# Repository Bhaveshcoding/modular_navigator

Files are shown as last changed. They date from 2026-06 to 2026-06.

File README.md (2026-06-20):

# Modular Navigator

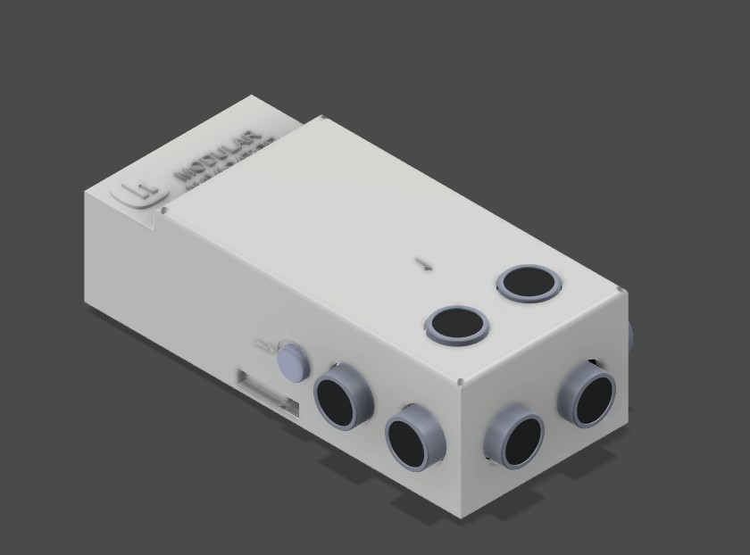
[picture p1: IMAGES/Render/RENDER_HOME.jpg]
Home Render


## Modular Haptic Navigation Device for the Visually Impaired

Modular Navigator is a portable assistive navigation device that provides directional haptic feedback for obstacle awareness.

The system uses four HC-SR04 ultrasonic sensors to monitor the area around the user. Distance measurements are processed by an ESP32, which activates vibration motors corresponding to the detected obstacle direction.

Unlike audio-based navigation aids, the device uses vibration feedback, allowing users to remain aware of surrounding sounds while receiving environmental information.

---

# Project Status

🚧 **Design & Engineering Phase**

Completed:

* CAD enclosure design
* Electronics architecture
* Wiring schematic
* Component selection
* Bill of Materials (BOM)
* Firmware planning
* Wokwi simulation setup
* Manufacturing file preparation

Planned:

* Physical assembly
* Firmware deployment
* Hardware validation
* Real-world testing
* Design iteration

---

# Motivation

Many assistive navigation devices are expensive, difficult to repair, or rely heavily on audio feedback. This project explores a low-cost, open-source alternative that provides directional obstacle awareness through haptic feedback.

The goal is to investigate whether commonly available components, 3D-printed parts, and open-source tools can be used to create a modular navigation aid that is easy to reproduce, modify, and improve.

# Repository Highlights

* Fusion 360 CAD source files
* STEP and STL exports
* ESP32 firmware
* Electronics documentation
* KiCad schematic
* Wiring diagram
* Bill of Materials
* Design journal
* Wokwi simulation
* Build instructions
* Assembly renders and exploded views

---

# Device Overview

The device monitors four directions:

* Front
* Left
* Right
* Downward

When an obstacle is detected, the corresponding vibration motor is activated.

| Hazard | Feedback |
| --- | --- |
| Obstacle on Left | Left vibration motor |
| Obstacle on Right  | Right vibration motor |
| Obstacle Ahead | Front vibration motor |
| Stairs / Drop-offs | Warning vibration pattern |

---

# Fully Assembled Device

## Front Render

Home Render

---

# Interactive 3D Model

[Open Interactive 3D Mesh Grid View](CAD%20files/Model/Model_with%20electronics/ModularNavigator_Enclosure_v1_with_electronics.stl)

The model contains:

* Enclosure
* ESP32
* Battery
* Charging system
* Ultrasonic sensors
* Vibration motors
* Internal mounting structure

---

# System Architecture

## 1. Sensing System

### Components

* 4× HC-SR04 Ultrasonic Sensors

### Coverage

| Sensor | Purpose |
| --- | --- |
| Front | Detect obstacles ahead |
| Left | Detect obstacles on the left  |
| Right | Detect obstacles on the right |
| Downward | Detect stairs and drop-offs |

---

## 2. Processing System

### Controller

* ESP32 Development Board

### Responsibilities

* Read sensor measurements
* Calculate distances
* Determine obstacle direction
* Generate haptic feedback
* Manage overall system operation

---

## 3. Haptic Feedback System

### Components

* 3× Coin Vibration Motors

### Motor Mapping

| Motor | Function |
| --- | --- |
| Left Motor  | Left obstacle warning  |
| Right Motor | Right obstacle warning |
| Front Motor | Front obstacle warning |

---

## 4. Power System

### Components

* 3.7V Li-Po Battery
* TP4056 Charging Module
* MT3608 Boost Converter

### Functions

* Battery charging
* Voltage regulation
* Portable operation

---

# How It Works

1. Ultrasonic sensors emit pulses.
2. Echo times are measured.
3. Distance is calculated by the ESP32.
4. Obstacle direction is determined.
5. Corresponding vibration motor is activated.
6. Feedback is provided to the user.

---

# Exploded Views

## Top Exploded View

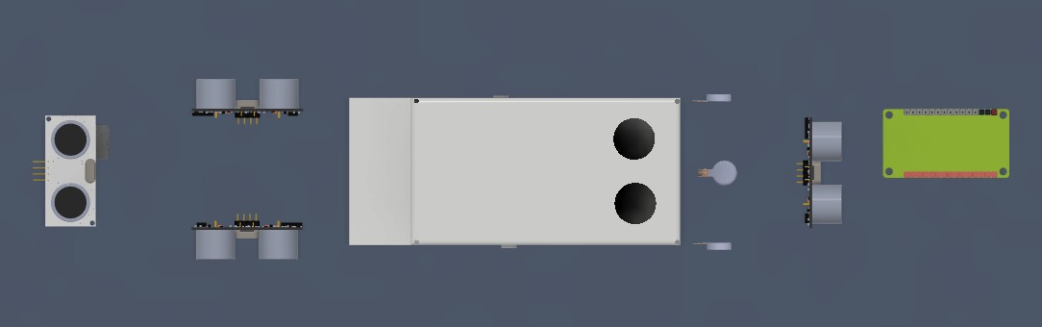
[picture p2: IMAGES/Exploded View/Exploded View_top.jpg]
Exploded Top


## Side Exploded View

Exploded Side

## Home Exploded View

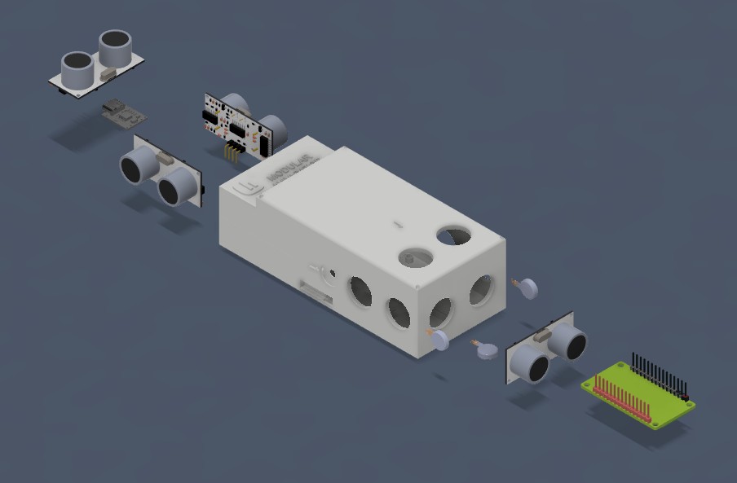
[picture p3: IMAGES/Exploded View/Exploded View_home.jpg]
Exploded Home

# Electronics

## Wiring Diagram

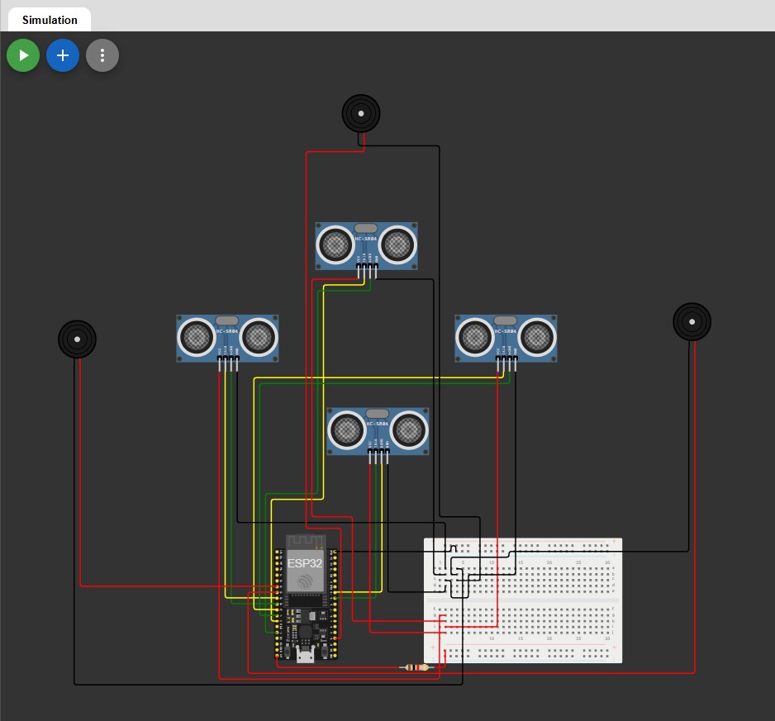
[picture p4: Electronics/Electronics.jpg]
Electronics Map



The wiring diagram documents the complete electrical system, including:

* ESP32 connections
* Ultrasonic sensors
* Vibration motors
* Battery system
* TP4056 charging module
* MT3608 boost converter
* Voltage divider circuits

---

# Hardware Used

| Component | Quantity | Purpose |
| --- | --- | --- |
| ESP32 Dev Board | 1 | Main controller |
| HC-SR04 Sensors | 4 | Obstacle detection  |
| Vibration Motors | 3 | Haptic feedback |
| TP4056 | 1 | Battery charging |
| MT3608 | 1 | Voltage boosting |
| 3.7V Li-Po Battery | 1 | Portable power |
| 2N2222 Transistors | 3 | Motor drivers |
| 1N4007 Diodes | 3 | Flyback protection  |
| Resistors | Multiple | Signal conditioning |

---

# Bill of Materials (BOM)

The complete BOM is available in:

```text
BOM.csv
```

## Total Cost

**$23.93 USD**

The design uses low-cost, commonly available components to keep the project accessible and easy to reproduce.

---

# PCB / Electronics Implementation

The current design uses direct wiring rather than a custom PCB.

Components are mounted inside the enclosure using dedicated mounting features included in the CAD design. Future revisions may use a custom PCB to reduce wiring complexity and improve manufacturability.

---

# Firmware

Firmware location:

```text
FIRMWARE/main.ino
```

Firmware responsibilities:

* Distance measurement
* Obstacle detection
* Direction classification
* Haptic feedback generation
* Continuous environmental monitoring

---

# Wokwi Simulation

Wokwi was used during development to validate the planned system architecture and firmware logic.

### Goals

* Validate GPIO assignments
* Verify sensor behavior
* Test vibration logic
* Debug firmware concepts

### Simulation Link

https://wokwi.com/projects/461725213892270081

---

# How To Build

## Step 1 – Print the Enclosure

Files:

```text
CAD files/Printing Parts/
```

Recommended settings:

* PLA
* 0.2 mm layer height
* 15–20% infill
* Supports where required

---

## Step 2 – Install Components

Install:

* ESP32 Development Board
* HC-SR04 Sensors
* Vibration Motors
* Li-Po Battery
* TP4056 Module
* MT3608 Module

Align all components with the mounting locations shown in the CAD model.

---

## Step 3 – Complete Wiring

Follow:

```text
Electronics/Electronics.md
```

and

```text
Electronics/Electronics.jpg
```

Important notes:

* Use voltage dividers on HC-SR04 ECHO pins.
* Connect all grounds together.
* Verify motor polarity.
* Verify battery polarity before powering the system.

---

## Step 4 – Upload Firmware

Open:

```text
FIRMWARE/main.ino
```

Upload the firmware using Arduino IDE.

Requirements:

* ESP32 board package
* USB cable
* Arduino IDE

---

## Step 5 – Final Assembly

* Route wires through the enclosure.
* Mount the ESP32, sensors, battery, TP4056, and MT3608 using the designed screw mounting points.
* Secure sensors using M1.6 fasteners where required.
* Attach the enclosure lid using M3 screws.
* Verify wiring before powering the device.

---

# Zine

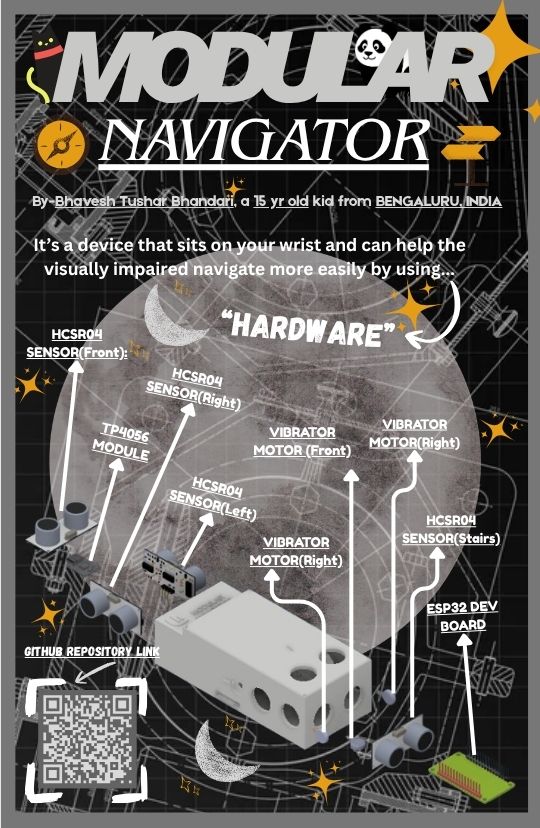
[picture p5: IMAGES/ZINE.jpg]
Zine


The project zine provides a visual overview of the concept and design process.
# Repository Structure

```text
├── CAD files
│   ├── Miscellaneous Parts_&_Images
│   ├── Model/Model_with electronics
│   └── Printing Parts/3D print
│
├── Electronics
│   ├── Electronics.jpg
│   ├── Electronics.md
│   └── Modular_navigator_schematic.kicad_sch
│
├── FIRMWARE
│   └── main.ino
│
├── IMAGES
│   ├── Exploded View
│   ├── Render
│   ├── ZINE.jpg
│   └── ZINE.pdf
│
├── BOM.csv
├── LICENSE
├── PLANNING DESIGN STAGE.md
├── modular-navigator-journal.md
├── README.md
└── .gitignore
```

---

# Planned Testing

The following tests will be performed after assembly:

| Test | Objective |
| --- | --- |
| Front Obstacle Detection | Verify forward sensing |
| Left Obstacle Detection | Verify left-side sensing |
| Right Obstacle Detection | Verify right-side sensing |
| Downward Hazard Detection | Verify stair and ledge detection |
| Haptic Feedback Validation  | Verify motor activation |
| Charging System Test | Verify charging functionality |
| Battery Runtime Test | Measure operating duration |
| Real-World Navigation Trial | Evaluate practical usability |

---

# Future Improvements

## Electronics

* Custom PCB
* Integrated charging circuitry
* Reduced wiring complexity
* Improved power efficiency

## Mechanical Design

* Waterproof enclosure
* Improved ergonomics
* Smaller enclosure
* Wearable mounting options

## Software

* Adjustable sensitivity
* Multiple vibration patterns
* Battery monitoring
* Power-saving modes

## Connectivity

* Bluetooth support
* Wireless configuration
* Mobile app integration
* OTA firmware updates

## Accessibility Features

* GPS-assisted navigation
* Voice guidance
* AI-powered object recognition
* Advanced hazard classification
* Route assistance features

---

# Contributing

Contributions, suggestions, and design improvements are welcome.

If you would like to build upon the project, feel free to fork the repository, modify the design, and submit improvements.

---

# License

See the `LICENSE` file for licensing information.

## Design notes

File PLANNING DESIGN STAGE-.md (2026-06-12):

# ***PLANNING DESIGN STAGE-***

### PROJECT-

Modular Smart Navigation Assist for the Visually Impaired

A clip on device for a white cane(i.e. device used by blind ppl).//UPDATED TO WIRST

##### 

##### MATERIALS NEEDED-

* 4 HC-SR04 ULTRASOUND SENSORS (front, left, right , down\[FOR STAIRS])
* ESP 32 DEV BOARD
* 3 VIBRATOR MOTORS-

  * Left object- Left motor
  * Right object- Right motor
  * Front object- Front motor
  * Down (stairs)- ALL Both long beep and long pause

&#x09;

##### Attachment Method-

&#x09;

Uses screws to attach to any cane.

##### Design Phase-

  * Circuit Diagram
  * Firmware Skeleton
  * CAD enclosure body
  * CAD clip on
  * BOM
  * README
  * GITHUB REPO

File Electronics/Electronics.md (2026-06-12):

# CORRECT WIRING DESIGN

##  Power System

- Battery → TP4056 (charging + protection)
- TP4056 OUT → MT3608 Boost → 5V output
- 5V → ESP32 VIN pin
- GND → Common everywhere

##  Ultrasonic Sensors Wiring

- Each Sensor:
  - VCC → 5V
  - GND → GND
  - TRIG → ESP32 GPIO
  - ECHO → Voltage Divider → ESP32 GPIO
- Voltage Divider (MANDATORY):
  - 1kΩ + 2kΩ resistors
  - Reduces 5V → ~3.3V

##  GPIO Mapping (Optimized)

| Sensor | TRIG | ECHO |
|---|---|---|
| Front  | GPIO 12 | GPIO 13 |
| Left | GPIO 25 | GPIO 26 |
| Right  | GPIO 27 | GPIO 14 |
| Down | GPIO 18 | GPIO 19 |

##  Vibration Motors Circuit

- Each Motor:
  - ESP32 GPIO → 1k resistor → Base of 2N2222
  - Emitter → GND
  - Collector → Motor (-)
  - Motor (+) → 5V
  - Diode across motor (reverse biased)
- GPIO:
  - Left Motor → GPIO 32
  - Right Motor → GPIO 33
  - Front Motor → GPIO 15

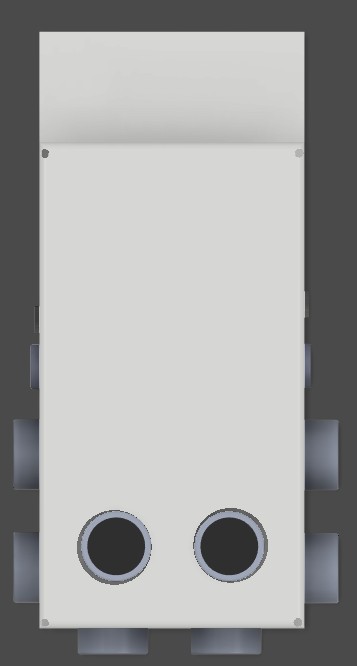
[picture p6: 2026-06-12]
IMAGES/Render/RENDER_TOP.jpg

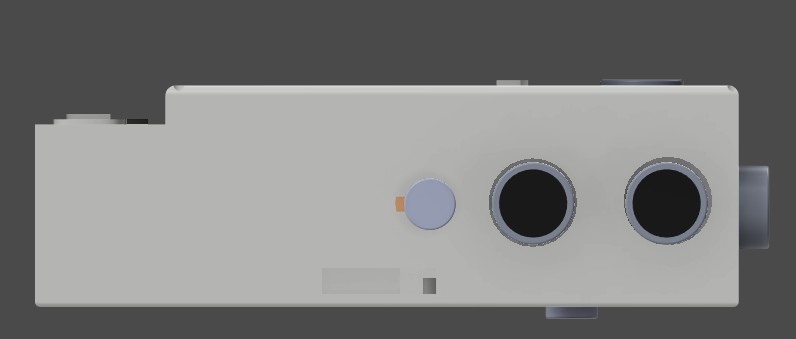
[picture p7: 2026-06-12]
IMAGES/Render/RENDER_SIDE.jpg

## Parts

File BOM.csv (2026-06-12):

Item No. | Component Name | Description | Qty | Unit Price (USD) | Total Price (USD) | Name of Buyer | Purchase Link
1.0 | ESP32 DevKit V1 | Main controller (WiFi + Bluetooth) | 1.0 | $4.75 | $4.75 | RoboticsDNA | https://roboticsdna.in/product/esp-wroom-32-wifi-bluetooth-networking-smart-component-development-board-30-pins/
2.0 | HC-SR04 Sensors | Ultrasonic distance modules | 4.0 | $1.07 | $4.28 | Amazon | https://www.amazon.in/TekBud-Ultrasonic-Distance-Detector-Robotics/dp/B0B5N57M79
3.0 | Coin Vibration Motors | Haptic feedback buzzers | 3.0 | $0.83 | $2.49 | Robu.in | https://robu.in/product/erm-coin-vibration-motor-12mm-dia-3-4mm-width
4.0 | 2N2222 Transistors | NPN switches for motor control | 3.0 | $0.097 | $0.291 | ElectronicsComp | https://www.electronicscomp.com/2n2222a-npn-bipolar-transistor-to-92-plastic-package
5.0 | 1N4007 Diodes | Flyback protection for motors | 3.0 | $0.021 | $0.063 | Quartz Comp | https://quartzcomponents.com/products/1n4007-diode
6.0 | 1kΩ Resistors | Current limiting (Transistor base) | 3.0 | $0.011 | $0.033 | flyrobo | https://www.flyrobo.in/planetary-geared-motor-24v-175rpm-100w?search=1k%20ohm%20resistor&description=1
7.0 | 3.7V Li-Po Battery | 500mAh–1000mAh battery | 1.0 | $0.95 | $0.95 | Amazon | https://www.amazon.in/Electron-500Mah-HCY-602030-R-41202096-Rechargeable/dp/B0DNY3TXRW
8.0 | TP4056 Charger | USB charging with protection | 1.0 | $0.19 | $0.19 | Robu.in | https://robocraze.com/products/tp4056-li-ion-battery-charging-module
9.0 | Jumper Wires (M-M) | Prototyping wires (20 pcs) | 1.0 | $0.28 | $0.28 | Robocraze | https://robocraze.com/products/m2m-jumper-wires-20cm-20pcs
10.0 | Jumper Wires (M-F) | Module connection wires (20 pcs) | 1.0 | $0.25 | $0.25 | Robocraze | https://robocraze.com/products/f2m-jumper-wires-20cm-20pcs
11.0 | Breadboard | 830-point board for testing | 1.0 | $0.59 | $0.59 | FLYRobu.in | https://www.flyrobo.in/mb102-830-points-solderless-prototype-pcb-breadboard-high-quality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
14.0 | 330Ω Resistor | Current limiting for LED | 1.0 | $0.011 | $0.011 | flyrobo | https://www.flyrobo.in/330-ohm-resistor
16.0 | 3D Printing Filament | PLA Material for enclosure/clips | 1.0 | $4.00 | $4.00 | Almighty Fila | https://almightyfila.com/product/pla-3d-printing-filament/
17.0 | Super Glue | Loctite Power Gel for assembly | 1.0 | $2.89 | $2.89 | Amazon | https://www.amazon.in/Loctite-Precision-Adhesive-Accurate-Materials/dp/B0001GRVPK?th=1
18.0 | M3 x 10mm Screws | Assembly hardware (6 pcs) | 6.0 | $0.019 | $0.114 | OnlyScrews | https://onlyscrews.in/products/phillips-pan-head-m3-x-10mm-pack-of-20
19.0 | M3 Hex Nuts | Assembly hardware (6 pcs) | 6.0 | $0.011 | $0.066 | OnlyScrews | https://onlyscrews.in/products/m3-nut-ss-304
20.0 | Foam Padding | Motor vibration isolation | 1.0 | $2.14 | $2.14 | Amazon | https://www.amazon.in/QTH-Thick-Foam-Sheet-Pack/dp/B083KLWNJR
21.0 | M1.6 Screws | Assembly hardware | 16.0 | $0.034 | $0.544 | OnlyScrews | https://onlyscrews.in/products/m1-6-x-5mm-phillips-round-head-laptop-and-mobile-screw-dia-1-6mm-length-5mm
 | GRAND TOTAL |  |  |  | $23.932

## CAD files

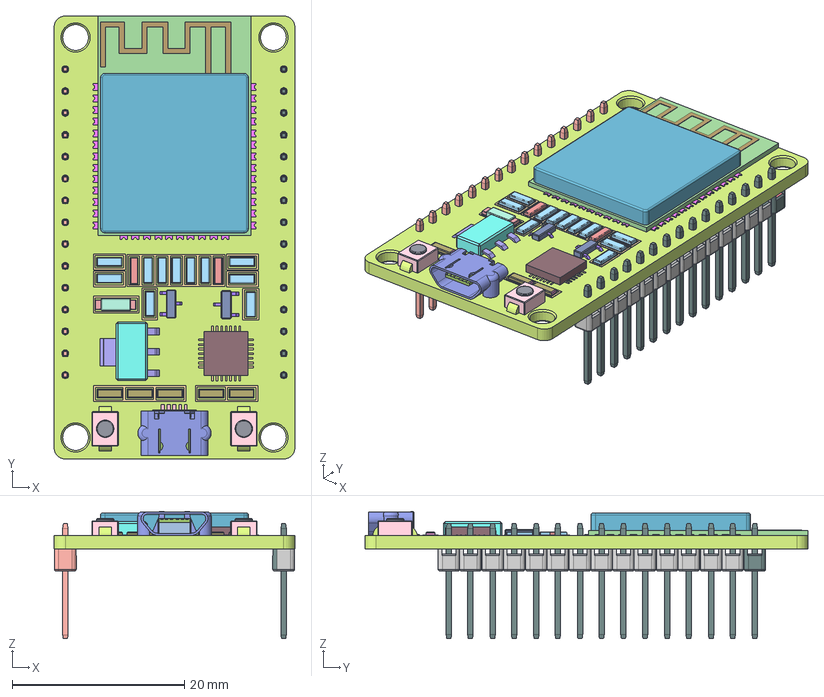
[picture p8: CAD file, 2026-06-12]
CAD files/Miscellaneous Parts_&_images/ESP32 dev board/ESP32 dev Kit v1.step
28.0 x 51.5 x 14.8 mm

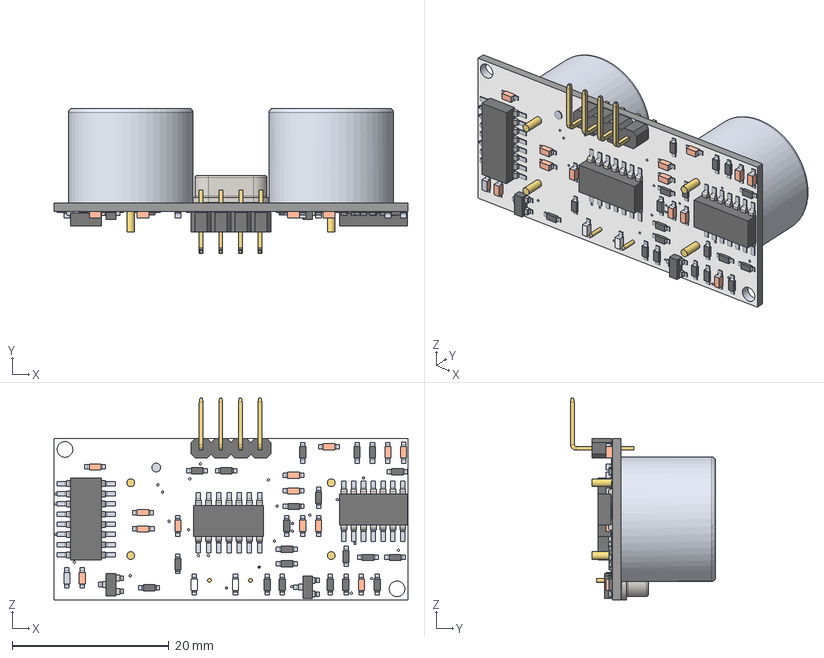
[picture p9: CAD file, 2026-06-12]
CAD files/Miscellaneous Parts_&_images/HCSRO4 sensor/hc-sr04.step
45.2 x 18.5 x 25.8 mm

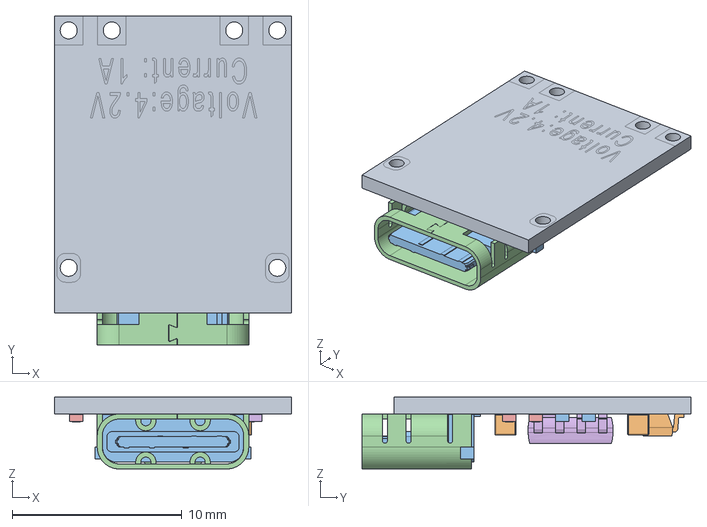
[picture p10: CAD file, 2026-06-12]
CAD files/Miscellaneous Parts_&_images/TP4056 MINI/TP4056 Mini.step
14.0 x 19.4 x 4.24 mm

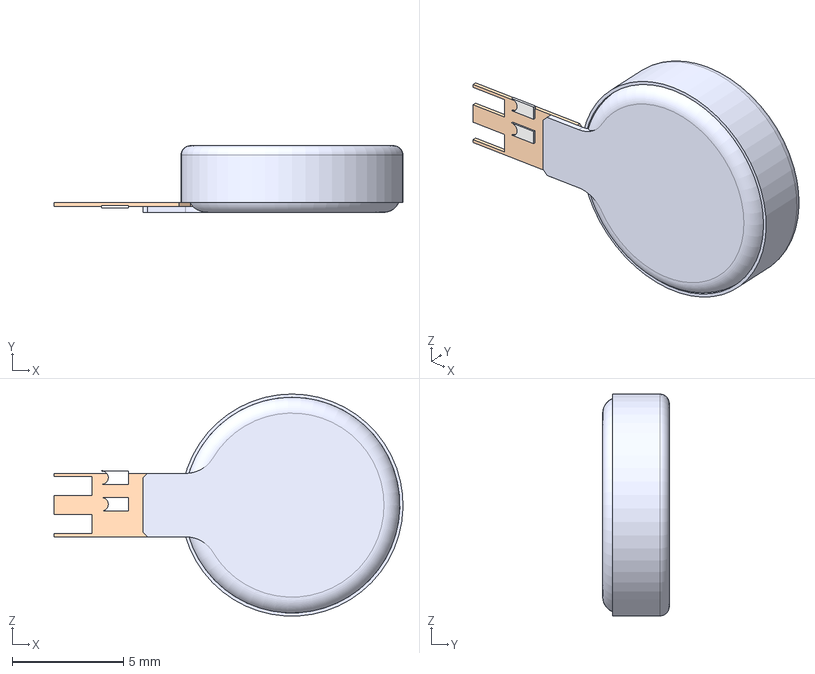
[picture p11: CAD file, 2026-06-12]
CAD files/Miscellaneous Parts_&_images/Vibrator Motor/Vibrator_motor.step
15.7 x 3.00 x 9.99 mm

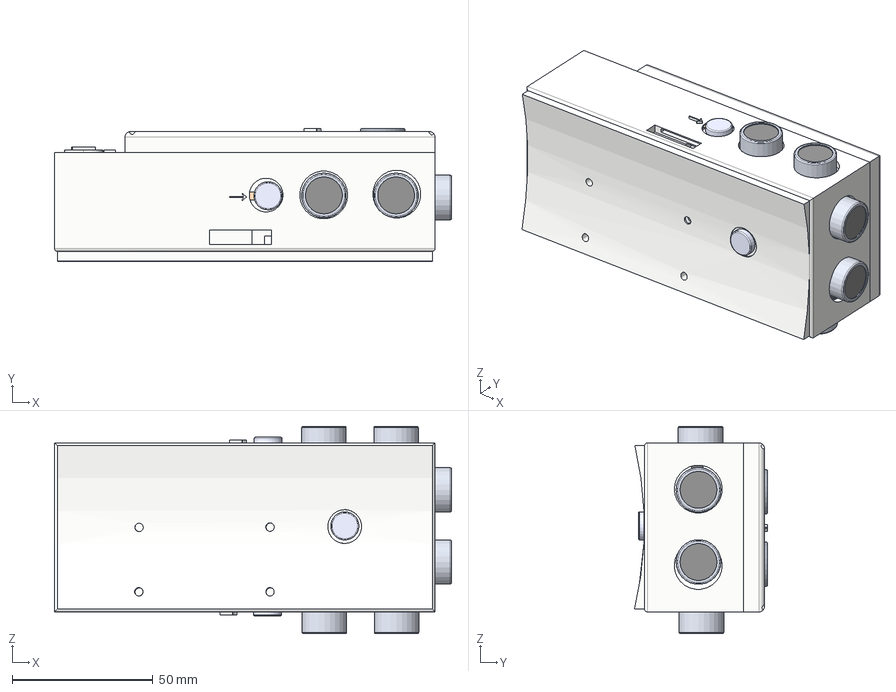
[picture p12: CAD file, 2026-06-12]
CAD files/Model/Model_with electronics/ModularNavigator_Enclosure_v1_with_electronics.step
140.8 x 47.2 x 73.6 mm

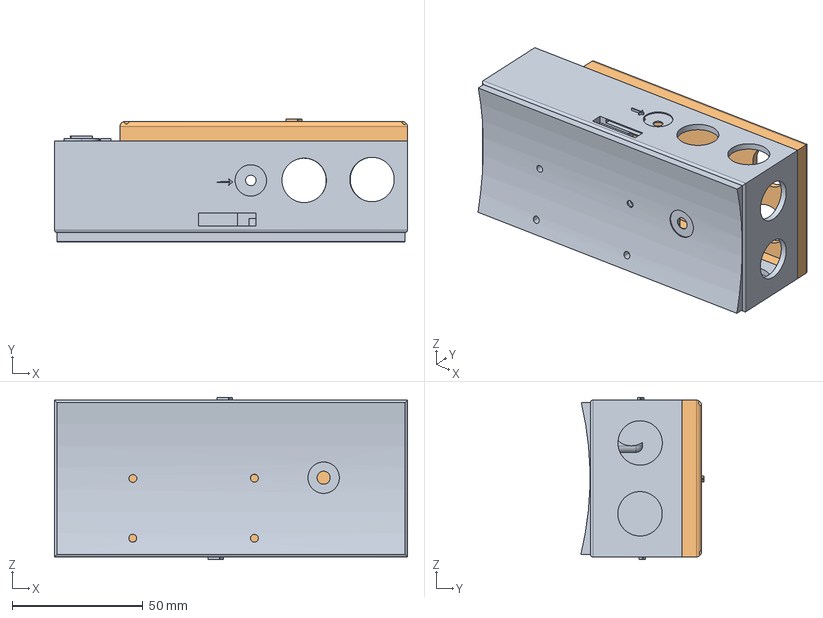
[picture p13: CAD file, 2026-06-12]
CAD files/Model/ModularNavigator_Enclosure_v1.step
135.0 x 47.1 x 62.0 mm

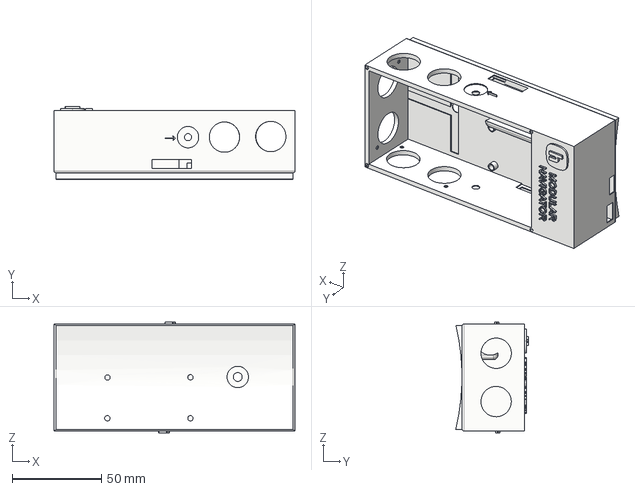
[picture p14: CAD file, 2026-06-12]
CAD files/Printing Parts/BODY print/ModularNavigator_Enclosure_v1.step
135.0 x 40.6 x 62.0 mm

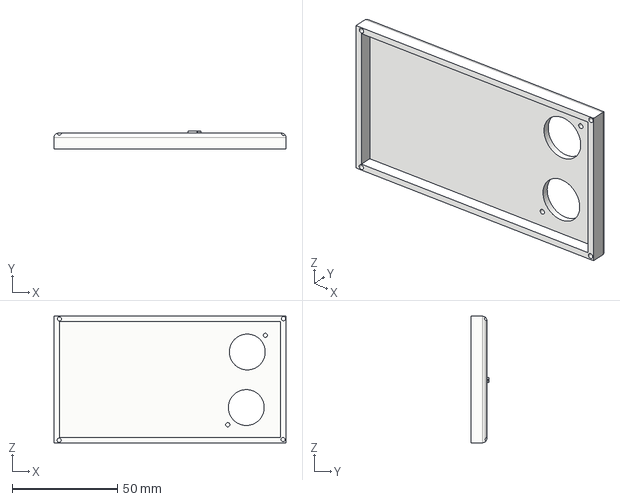
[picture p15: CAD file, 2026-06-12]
CAD files/Printing Parts/LID print/ModularNavigator_Enclosure_v1.step
110.0 x 8.50 x 60.0 mm

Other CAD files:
CAD files/Miscellaneous Parts_&_images/ESP32 dev board/ESP32 dev Kit v1.f3d
CAD files/Miscellaneous Parts_&_images/HCSRO4 sensor/hc-sr04.f3d
CAD files/Miscellaneous Parts_&_images/TP4056 MINI/TP4056 Mini.f3d
CAD files/Miscellaneous Parts_&_images/Vibrator Motor/Vibrator_motor.f3d
CAD files/Model/Model_with electronics/ModularNavigator_Enclosure_v1_with_electronics.f3z
CAD files/Model/Model_with electronics/ModularNavigator_Enclosure_v1_with_electronics.stl
CAD files/Model/ModularNavigator_Enclosure_v1.f3d
CAD files/Printing Parts/BODY print/ModularNavigator_Enclosure_v1.f3d
CAD files/Printing Parts/LID print/ModularNavigator_Enclosure_v1.f3d

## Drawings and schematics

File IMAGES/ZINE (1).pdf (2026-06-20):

# MODULAR

# NAVIGATOR

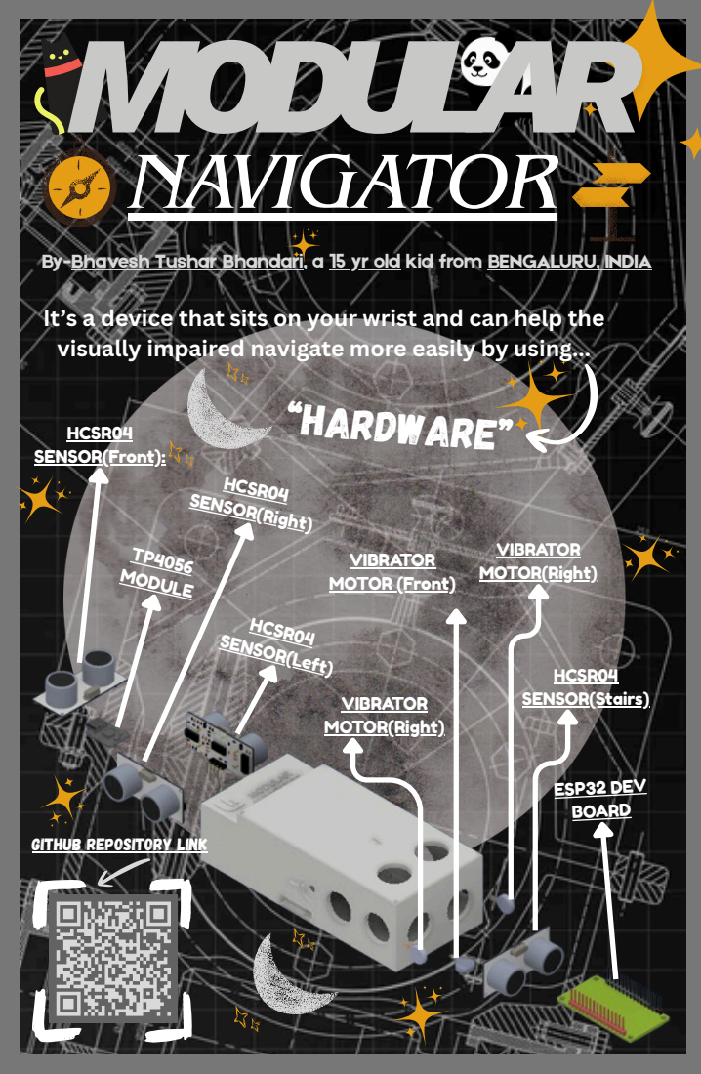
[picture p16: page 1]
“hardware”; HCSR04 SENSOR(Right); HCSR04 SENSOR(Front):; TP4056 MODULE; VIBRATOR MOTOR(Right); HCSR04 ENSOR(Left); VIBRATOR MOTOR (Front); HCSR04 SENSOR(Stairs); ESP32 DEV BOARD

By-Bhavesh Tushar Bhandari, a 15 yr old kid from BENGALURU, INDIA

It’s a device that sits on your wrist and can help the
visually impaired navigate more easily by using...

GITHUB REPOSITORY LINK

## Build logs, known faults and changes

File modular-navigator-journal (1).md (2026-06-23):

# Modular Navigator — Journal Export

- Exported at: 2026-06-23T11:46:14Z
- Project ID: 2297
- Entries: 13

## Entry 1
- ID: 2904
- Author: bhaveshtushar123
- Created At: 2026-04-19T16:01:04Z

### Content

Today I worked on both the planning and building parts of my Smart Navigation Assist project. I finished the parts, which are an ESP32, four ultrasonic sensors, and three buzzers for simulation. I also made sure that all the GPIO connections were correct. I made the circuit virtually on Wokwi (IT'S SO GUD!!) to make sure everything worked before I used real hardware. 

 I tested each part on its own, starting with the four sensors and then the buzzers. The buzzers worked fine, but the sensors first gave back 0 or strange values. After fixing the code, I realized that the TRIG sends a pulse and the ECHO only goes HIGH when sound reflects. Distance reads 0 or max if there is no object and ECHO stays LOW. It's not really analog; it's more like timed digital pulses.

This was helpful as i understood working of HC-SR04 sensor(Very important for project). 

DESIGN PLAN-



ELECTRONICS MAP(wowki)-



WOWKI LINK: https://wokwi.com/projects/461725213892270081 (TA DA!)

### Recording Links

- https://lookout.hackclub.com/api/media/96f04053-6852-4a52-a8ff-21b72b4bf49e/video.mp4
- https://lookout.hackclub.com/api/media/53afaf1c-2f9a-4fce-b0c6-5a0598f88462/video.mp4
- https://lookout.hackclub.com/api/media/14849718-619d-4b8d-9584-e350c174495b/video.mp4

## Entry 2
- ID: 3078
- Author: bhaveshtushar123
- Created At: 2026-04-20T18:08:50Z

### Content

Today was actually pretty productive :) I worked on the planning + build phase of my smart navigation project and finalized the BOM (shown below)!! I also spent time finding the cheapest links for all components since Hack Club is a non-profit, so I had to keep costs low. That part was kinda tiring but also satisfying when I found good deals!!

Then I worked on electronics + code and ran into errors. PlatformIO wasn’t configured properly, so Arduino.h wasn’t detected, which confused me at first! After fixing the setup, things started working properly :)

For the code , it reads distances from 4 ultrasonic sensors and converts that into vibration patterns. Closer objects mean faster signals!! The stair sensor overrides everything and triggers a danger alert. I also used millis() instead of delay, which is better.

Overall, good progress today and I understand the system much better now :)
BOM-

### Recording Links

- https://lookout.hackclub.com/api/media/5db7f4ff-165c-4a4a-be43-da1a6d484d4a/video.mp4
- https://lookout.hackclub.com/api/media/343b3d40-4925-427c-8789-cf96c91a24fc/video.mp4
- https://lookout.hackclub.com/api/media/900eb3fd-bc9a-4b2e-97f7-78493046b0a4/video.mp4
- https://lookout.hackclub.com/api/media/8d682762-4cff-43d3-89aa-19d1b9be344a/video.mp4

## Entry 3
- ID: 3235
- Author: bhaveshtushar123
- Created At: 2026-04-21T16:50:50Z

### Content

My project made a lot of progress today. Before I built the hardware, I tested some simple code in Wokwi to make sure everything worked. It felt great that nothing broke this time, lol. After that, I opened CAD and started working on the design of the enclosure.

I started by making the main box, which was 110 × 60 mm and 35 mm thick. This made it feel more like a real product than just an idea. Then I used the shell tool (2.5 mm thick) to hollow it out. That part was very satisfying.LOL!

Then I drew a layout sketch and marked where everything goes. The battery goes on the side, and the ESP32 goes in the middle (it finally looks neat!). Then I cut the battery slot (70 × 20 × 20 mm), and added 4 standoffs (5 mm height) for the ESP32.

Overall, super productive day! Getting closer!!

CAD1-

CAD2(HOME)-


### Recording Links

- https://lookout.hackclub.com/api/media/5ed5bc85-adbe-401a-947a-045290d420cb/video.mp4
- https://lookout.hackclub.com/api/media/3a09da94-43e3-47b6-b38f-2f5fbf61b901/video.mp4

## Entry 4
- ID: 3430
- Author: bhaveshtushar123
- Created At: 2026-04-22T18:38:17Z

### Content

Today was CAD-3, and to be honest, this is when things started to feel REAL. I worked on making the enclosure more than just a box.

First, I put the battery slot in the right place and made sure the battery fits snugly (not like before, when it slid around ). Then I worked on the motor slots and made sure they were close to the outer walls so that vibrations could be felt properly. This part was kind of fun, to be honest.

After that, I added wire channels (which are kind of annoying but very important) so that everything doesn't turn into a spaghetti mess later . I also made the USB cutout, which made it seem like a real device you could use.

Lastly, I put in screw posts so the lid could be attached later. This made the product feel more real.

This phase was mostly about structure and usability, and it went pretty well .







### Recording Links

- https://lookout.hackclub.com/api/media/423e5552-8347-4475-8429-093e74d94d92/video.mp4
- https://lookout.hackclub.com/api/media/63656baf-0228-4f70-aee8-f9e23df55114/video.mp4

## Entry 5
- ID: 3592
- Author: bhaveshtushar123
- Created At: 2026-04-23T18:26:58Z

### Content

Today I worked on Phase 4, which is basically making my design look like a real product. Yay! First, I made the lid by choosing the top face and moving it back a little bit (+0.3 mm) so that it fits and doesn't get stuck. That little thing seemed important because the lid wouldn't close right without it.

Then I made it a separate body by extruding it to 3 mm. 
Next, I made sure the screw holes were in the right place by projecting the posts and cutting through the lid. This part needed some attention, but it worked out.

Finally, I put fillets on the edges, and right away, everything looked smoother and more professional. But, I still have to make it BETTER by adding some engravings.

CAD-






### Recording Links

- https://lookout.hackclub.com/api/media/73b901b1-3a20-4689-9d5b-a9be1ca990f6/video.mp4

## Entry 6
- ID: 3742
- Author: bhaveshtushar123
- Created At: 2026-04-24T18:01:52Z

### Content

Today I worked on finishing Phase 4 and adding the final touches to my enclosure. I focused a lot on engraving, where I added the “Modular Navigator” text and worked on placing the logo properly on the lid. Getting the engraving to look clean and readable took some effort, but it made the design feel way more like a real product, yay!!

I also did some renders to see how everything looks visually, and it actually came out pretty clean and professional. But when I tried fitting the electronics, Irealisedd something annoying—the HC-SR04 sensors fit, but the module with screws doesn’t align properly inside. That means I’ll have to redo that part of the design.

Honestly, that part was kinda frustratin,g and I was a bit bummed, but it helped me understand how important exact fitting is.

CAD-
****


THE SAD IMAGE(not fitting screw holes)-


### Recording Links

- https://lookout.hackclub.com/api/media/28c2841d-0a9f-4278-8184-a3d06a9b7f96/video.mp4
- https://lookout.hackclub.com/api/media/6947c273-2639-4015-b042-9eb7b65ec9cb/video.mp4

## Entry 7
- ID: 3909
- Author: bhaveshtushar123
- Created At: 2026-04-25T18:51:41Z

### Content

Today was lowkey painful ngl like DAMN!… like I thought I was done but nah, esp32 said not today bruh!!! The raised parts and GPIO pins were taking way too much space, so I had to fix that whole setup again. spent time trying to align it properly so it actually fits inside and doesn’t clash with everything.

Then I added the TP4056 and space for vibrator motors, which was fine, but I also just added more chaos inside. After that, I flipped the ESP322 upside down (DUH! should’ve done earlier), but that decision literally forced me to redo so much stuff. like delete parts, rebuild, re-align everything… even had to redo renders again,n which was just annoying.

felt kinda bummed for a bit, but yeah,eah it’s cleaner now and makes more sense. still sucks to redo work but whatever, progress I guess… yay!!!
(Didn't wanna show my SPOTIFY 'cause I be gatekeeping those secret bangers, so I blacked it :0...)

CAD-


TP4056 module-


### Recording Links

- https://lookout.hackclub.com/api/media/2d840e0a-9092-4c45-9d23-45d74c9bf7ce/video.mp4
- https://lookout.hackclub.com/api/media/091ea328-86c9-4908-a11b-210ea019d73d/video.mp4

## Entry 8
- ID: 4231
- Author: bhaveshtushar123
- Created At: 2026-04-27T15:49:31Z

### Content

### CAD DONE!!!!!!!!
So today I finally pulled everything together and it actually feels kinda crazy how it all came from just an idea. I started by building the full tool and then designing the complete model with all the electronics inside like the ESP32, HC-SR04 sensors, battery and motors. Getting everything to fit properly was honestly a bit chaotic but also really satisfying when it started making sense.

Then I made sure the design is actually printable by splitting it into two parts — the main body and the lid. That part felt super important because now it’s not just a model, it’s something I can build. After that I exported everything properly in the right formats, including all components and final assembly files.

At the end I did a full check to confirm everything fits, aligns and works together. It’s kinda crazy seeing it all come together like this, feels like a real product now!!!
CAD-


FORMAT-


### Recording Links

- https://lookout.hackclub.com/api/media/d19717d9-c4b5-441b-87ff-131563277f09/video.mp4
- https://lookout.hackclub.com/api/media/eadbcab1-22cb-4a26-bcb6-073bb4b85df5/video.mp4
- https://lookout.hackclub.com/api/media/ea39bc07-2de4-4cb9-abf3-7bb2e0203fa0/video.mp4

## Entry 9
- ID: 4367
- Author: bhaveshtushar123
- Created At: 2026-04-28T17:21:37Z

### Content

Today was mostly about checking and fixing everything before the final submission, and it felt pretty serious. First, I went through all my files to make sure nothing was missing or messed up. I checked the CAD files, exports, and made sure everything was saved and organized properly. Then, I looked over the actual design again to ensure that all the electronics and parts could be assembled correctly. I focused on whether the screws aligned and if everything fit together without any issues.

I realized I needed to update my BOM, so I added M1.5 screws since they are necessary for proper assembly. It’s a small detail, but important. After that, I worked on designing my zine page, placing all the parts, arrows, names, and descriptions to clearly explain the project flow.

Today involved more polishing than building, but it made everything feel complete and ready. It was a bit stressful, but also satisfying.

DESIGN OF ZINE-


### Recording Links

- https://lookout.hackclub.com/api/media/6c405dc1-6fa2-44d5-b7a3-46857ac3f703/video.mp4
- https://lookout.hackclub.com/api/media/cc263992-36df-4851-ad57-1e389c6b53d3/video.mp4

## Entry 10
- ID: 4652
- Author: bhaveshtushar123
- Created At: 2026-04-30T18:12:37Z

### Content

I officially started working on the zine page. At first, it was a little hard to understand, but after watching a tutorial and playing around with Canva (I couldn't use "Figma"), it got easier.

Most of the time, I worked on the layout, putting the main render in place and using arrows to point out certain details. I added short bits of information about important parts like the sensors, ESP32, and motors. This really helps with the design. It was also a big win to make an exploded view of the model.

Lastly, I made sure that all of my renders and CAD files were up to date with the most recent version of the design.  There is still some work to be done, but it is definitely coming together.

Zine-


### Recording Links

- https://lookout.hackclub.com/api/media/b7a7cff3-e07d-4ab3-aac9-778835807ab3/video.mp4
- https://lookout.hackclub.com/api/media/3287fb53-a642-45c7-85d9-3a113e105071/video.mp4
- https://lookout.hackclub.com/api/media/205045d2-c9c9-45f0-9262-d10a84d71213/video.mp4

## Entry 11
- ID: 5473
- Author: bhaveshtushar123
- Created At: 2026-05-04T18:52:26Z

### Content

today was mostly spent on the zine. It was a bit tiring, but it came together slowly. I worked on improving the page by adding a proper background, so it doesn’t look plain and lifeless anymore. Then I fixed all the arrows and changed them to elbowed lines. This made everything look much cleaner and less messy; I should have done it earlier.

I also added a random QR code as a placeholder just to see how the layout feels. I included some small graphics to make it resemble an actual product poster instead of just text and arrows. I spent some time aligning everything repeatedly, which was frustrating but necessary.

Apart from that, I watched two videos on learning schematics to understand wiring better for later. I’m still not perfect, but it makes more sense now.

Overall, it wasn't crazy progress, but the zine is definitely looking more real now.

ZINE-


### Recording Links

- https://lookout.hackclub.com/api/media/ce6fe15e-834e-4045-8668-9e022f48d653/video.mp4
- https://lookout.hackclub.com/api/media/66f07286-a9a8-4bb4-b993-480516237776/video.mp4

## Entry 12
- ID: 5880
- Author: bhaveshtushar123
- Created At: 2026-05-07T11:59:36Z

### Content

today was basically the final design wrap-up for modular navigator. i focused on initializing and properly organizing the github repo so the entire project finally feels complete instead of scattered files everywhere. i spent most of the time polishing the README and making sure every part of the project is documented clearly.

i added renders, exploded views, electronics diagrams, BOM details, build instructions, wiring explanations, and project overview sections so someone can actually understand the project without opening random files. i also fixed image paths, repo structure, and markdown formatting multiple times because github kept breaking things for no reason bruh.

after linking the wokwi simulation and checking all sections again, the repo finally started looking like an actual hardware project page instead of just a school submission. honestly kinda satisfying seeing months of cad, electronics, renders, and planning finally come together into one clean project yay.



### Recording Links

- https://lookout.hackclub.com/api/media/caa193bd-7192-4a94-b201-3c31cb57cca8/video.mp4
- https://lookout.hackclub.com/api/media/7c677bcb-d69a-49c9-9ae0-a382d7045f99/video.mp4
- https://lookout.hackclub.com/api/media/55e0987d-192f-4803-be52-8eae9077e8dd/video.mp4

## Entry 13
- ID: 10907
- Author: bhaveshtushar123
- Created At: 2026-06-01T15:10:49Z

### Content

Today I worked on improving the project based on feedback from the review. The main thing was redesigning parts of the enclosure to make it more ergonomic since it is supposed to be held in the hand. I adjusted the shape and dimensions to make it feel more natural and comfortable instead of just being a box with electronics inside.

I also worked on creating proper renders of the assembly instead of only using CAD screenshots so the project would be easier to understand visually. Along with that, I cleaned up the documentation, added a clearer schematic using KiCad, and spent time reorganizing the README and Zine. The previous version felt cluttered, so I focused on making the information simpler, cleaner, and easier to follow while still keeping all the important details.





### Recording Links

- https://lookout.hackclub.com/api/media/35165ba0-d3d3-4aff-8a0c-4b5a91b9af9a/video.mp4
- https://lookout.hackclub.com/api/media/3292b898-d1c0-4b58-bb1a-48362d67378f/video.mp4
- https://lookout.hackclub.com/api/media/ac7a411d-8a35-46be-9cc5-dfa493c08281/video.mp4

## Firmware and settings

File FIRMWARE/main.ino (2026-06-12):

// ============================================================
//  MODULAR SMART NAVIGATION ASSIST — ESP32 Firmware
// ============================================================


#include <Arduino.h>

// ── PIN DEFINITIONS ─────────────────────────────────────────

#define TRIG_FRONT  12
#define ECHO_FRONT  13

#define TRIG_LEFT   25
#define ECHO_LEFT   26

#define TRIG_RIGHT  27
#define ECHO_RIGHT  14

#define TRIG_STAIR  18
#define ECHO_STAIR  19

#define MOTOR_LEFT   32
#define MOTOR_RIGHT  33
#define MOTOR_FRONT  15

// ── DISTANCE THRESHOLDS ─────────────────────────────────────
#define DIST_NEAR      30
#define DIST_MEDIUM    70
#define DIST_FAR      150

#define STAIR_DROP     50

// ── TIMING ──────────────────────────────────────────────────
#define PULSE_SLOW_ON    200
#define PULSE_SLOW_OFF   600
#define PULSE_FAST_ON    150
#define PULSE_FAST_OFF   150
#define STAIR_LONG_ON    500
#define STAIR_PAUSE      300

#define SENSOR_INTERVAL  60

// ── PWM ─────────────────────────────────────────────────────
#define MOTOR_STRENGTH  200

#define CH_LEFT   0
#define CH_RIGHT  1
#define CH_FRONT  2
#define PWM_FREQ  5000
#define PWM_RES   8

enum VibeState { SILENT, SLOW_PULSE, FAST_PULSE, CONTINUOUS };

// ── GLOBALS ─────────────────────────────────────────────────
float distFront, distLeft, distRight, distStair;

unsigned long lastSensorRead = 0;
unsigned long lastPulseToggle[3] = {0,0,0};
bool pulseOn[3] = {false,false,false};

bool stairActive = false;
unsigned long stairPatternStart = 0;

// ── FUNCTIONS ───────────────────────────────────────────────

float readDistance(int trigPin, int echoPin) {
  digitalWrite(trigPin, LOW);
  delayMicroseconds(2);
  digitalWrite(trigPin, HIGH);
  delayMicroseconds(10);
  digitalWrite(trigPin, LOW);

  long duration = pulseIn(echoPin, HIGH, 30000);
  if (duration == 0) return 999;
  return duration * 0.0343 / 2;
}

VibeState getVibeState(float dist) {
  if (dist <= 0 || dist > DIST_FAR) return SILENT;
  if (dist <= DIST_NEAR) return CONTINUOUS;
  if (dist <= DIST_MEDIUM) return FAST_PULSE;
  return SLOW_PULSE;
}

void runMotor(int channel, bool on) {
  ledcWrite(channel, on ? MOTOR_STRENGTH : 0);
}

void stopAllMotors() {
  ledcWrite(CH_LEFT, 0);
  ledcWrite(CH_RIGHT, 0);
  ledcWrite(CH_FRONT, 0);
}

void handlePulse(int channel, VibeState state, unsigned long now) {
  switch(state) {
    case SILENT:
      runMotor(channel,false);
      break;

    case CONTINUOUS:
      runMotor(channel,true);
      break;

    case SLOW_PULSE:
    case FAST_PULSE: {
      unsigned long onTime  = (state == SLOW_PULSE) ? PULSE_SLOW_ON : PULSE_FAST_ON;
      unsigned long offTime = (state == SLOW_PULSE) ? PULSE_SLOW_OFF : PULSE_FAST_OFF;

      unsigned long elapsed = now - lastPulseToggle[channel];
      unsigned long limit = pulseOn[channel] ? onTime : offTime;

      if (elapsed >= limit) {
        pulseOn[channel] = !pulseOn[channel];
        runMotor(channel, pulseOn[channel]);
        lastPulseToggle[channel] = now;
      }
      break;
    }
  }
}

void runStairPattern(unsigned long now) {
  if (stairPatternStart == 0) stairPatternStart = now;

  unsigned long e = now - stairPatternStart;

  if (e < STAIR_LONG_ON) {
    runMotor(CH_LEFT,true);
    runMotor(CH_RIGHT,true);
    runMotor(CH_FRONT,true);
  }
  else if (e < STAIR_LONG_ON + STAIR_PAUSE) {
    stopAllMotors();
  }
  else if (e < 2*STAIR_LONG_ON + STAIR_PAUSE) {
    runMotor(CH_LEFT,true);
    runMotor(CH_RIGHT,true);
    runMotor(CH_FRONT,true);
  }
  else if (e < 2*STAIR_LONG_ON + 2*STAIR_PAUSE) {
    stopAllMotors();
  }
  else {
    stairPatternStart = now;
  }
}

// ── SETUP ───────────────────────────────────────────────────
void setup() {
  Serial.begin(115200);

  int trigPins[] = {12,25,27,18};
  int echoPins[] = {13,26,14,19};

  for(int i=0;i<4;i++){
    pinMode(trigPins[i], OUTPUT);
    pinMode(echoPins[i], INPUT);
  }

  ledcSetup(CH_LEFT, PWM_FREQ, PWM_RES);
  ledcSetup(CH_RIGHT, PWM_FREQ, PWM_RES);
  ledcSetup(CH_FRONT, PWM_FREQ, PWM_RES);

  ledcAttachPin(MOTOR_LEFT, CH_LEFT);
  ledcAttachPin(MOTOR_RIGHT, CH_RIGHT);
  ledcAttachPin(MOTOR_FRONT, CH_FRONT);

  stopAllMotors();
}

// ── LOOP ────────────────────────────────────────────────────
void loop() {
  unsigned long now = millis();

  if (now - lastSensorRead >= SENSOR_INTERVAL) {
    lastSensorRead = now;

    distFront = readDistance(TRIG_FRONT, ECHO_FRONT);
    distLeft  = readDistance(TRIG_LEFT,  ECHO_LEFT);
    distRight = readDistance(TRIG_RIGHT, ECHO_RIGHT);
    distStair = readDistance(TRIG_STAIR, ECHO_STAIR);

    Serial.printf("F:%.1f L:%.1f R:%.1f D:%.1f\n",
      distFront, distLeft, distRight, distStair);

    stairActive = (distStair > STAIR_DROP);
  }

  if (stairActive) {
    runStairPattern(now);
    return;
  }

  stairPatternStart = 0;

  handlePulse(CH_LEFT,  getVibeState(distLeft),  now);
  handlePulse(CH_RIGHT, getVibeState(distRight), now);
  handlePulse(CH_FRONT, getVibeState(distFront), now);
}
